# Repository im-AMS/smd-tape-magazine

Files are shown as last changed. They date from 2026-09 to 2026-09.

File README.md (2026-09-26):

# SMD Tape Magazine: parametric

A fully parametric FreeCAD model of an SMD component tape magazine for 8, 12
and 16 mm tape, plus a sticker generator that prints matching labels for each
magazine.

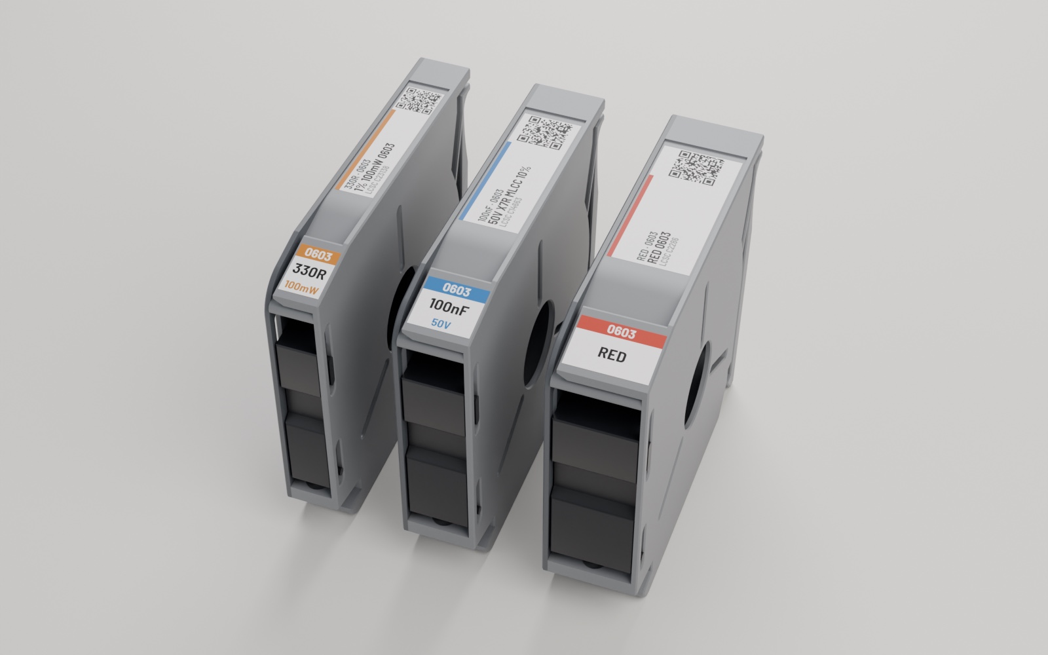
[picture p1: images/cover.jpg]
8, 12 and 16 mm magazines with stickers


| 8 mm magazine | lid latches |
|---|---|
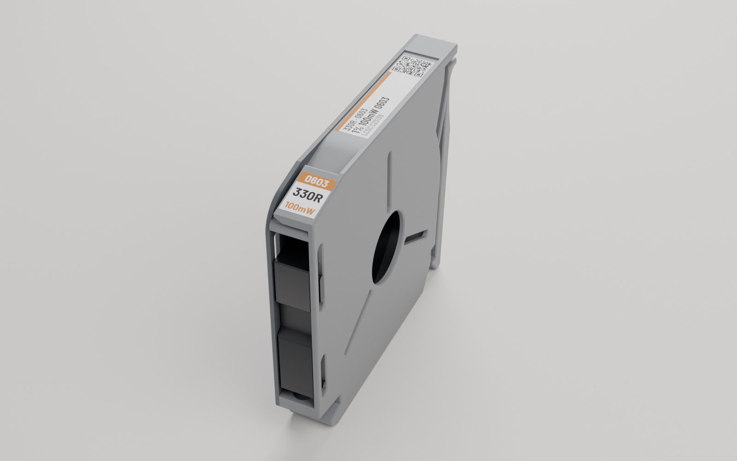
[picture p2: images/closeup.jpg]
8 mm magazine close-up
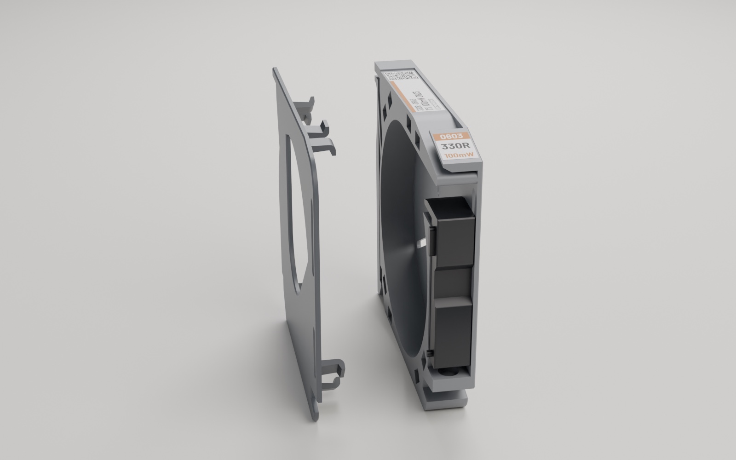
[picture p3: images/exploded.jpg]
Lid pulled off to show the snap pegs
|  |  |

## What's in here

| path | what |
|---|---|
| `print/` | print-ready STLs: `smd-magazine-body-{8,12,16}mm`, `smd-magazine-slider-{8,12,16}mm`, `smd-magazine-lid-all-sizes` |
| `print/rails/` | rails to stand the magazines in, from the two earlier versions of this design (their own licenses, see [rails/README](print/rails/README.md)) |
| `cad/smd-tape-magazine.FCStd` | the parametric FreeCAD model (FreeCAD 1.1+): magazine, lid, slider, parameters |
| `cad/latch-socket-cutter.FCStd`, `cad/latch-peg.FCStd` | the lid latch shapes, linked into the main file. Keep all three files together |
| `stickers/` | label generator: front + top stickers per part, laid out on A4 |
| `docs/DESIGN.md` | how the model is built, measured dimensions, and known traps |

## Print

**Print in PETG only.** The lid holds on with eight small snap pegs; PLA is
too brittle for them and they snap off.

The STLs are already oriented: the chamfered face goes on the bed (it's there
to absorb elephant's foot). No supports needed.

| setting | value |
|---|---|
| material | PETG |
| nozzle | 0.4 mm |
| layer height | 0.25 mm |
| walls | 3 |
| top / bottom shells | 3 / 3 |
| infill | 8–10% gyroid (a little infill makes the print itself more reliable) |
| supports | none |

**Tune your filament profile first**, especially **bridging and cooling**.
The latch sockets and pegs are small, and sagging bridges or under-cooled
overhangs are the usual cause of a lid that won't fit or won't stay on.

Per magazine: one body, one slider of the same width, one lid, and a spring.
For the rail, pick one from [`print/rails/`](print/rails/README.md).

### Loader (recommended)

Print Robin's [SMD Magazine Loader](https://www.printables.com/model/468303-smd-magazine-loader)
too. It makes refilling a magazine with tape quick and easy. **These
magazines are compatible with it**; the design they were remixed from is not.

### Fitting the lid

Press the lid on **evenly**, with something flat and stiff laid over it, e.g.
a ~3 mm mild steel plate, so all eight pegs snap in together. Pressing one
corner at a time bends the lid and can break a peg.

### Spring

The slider's spring bore is 8 mm deep, made for a longer spring than
upstream's. Upstream's spring is 0.3 mm wire × 4 mm OD × 20 mm with a 5 mm
bore. To use that one, set `spring_pocket` to 5 (see below).

## Customise

Open `cad/smd-tape-magazine.FCStd` in FreeCAD 1.1 or newer and double-click
`Parameters`. The sheet is colour-coded:

- **green: user inputs.** `tape_size` (8 / 12 / 16), `clearance`, `wall`,
  `spring_pocket`
- **yellow: fit tuning.** `peg_gap`: raise it if the lid is too tight to push
  on with your printer
- **grey: derived / internal.** Calculated from the above; don't type over them

After changing a value press **Ctrl+R** (Edit → Refresh). Then select the
`Magazine`, `Lid` or `Slider` body and export it as STL.

## Stickers

`stickers/` generates two labels per part from a CSV parts list: a front
label for the dispensing end and a top strip with value, package and a QR
code, sized to the magazine width.

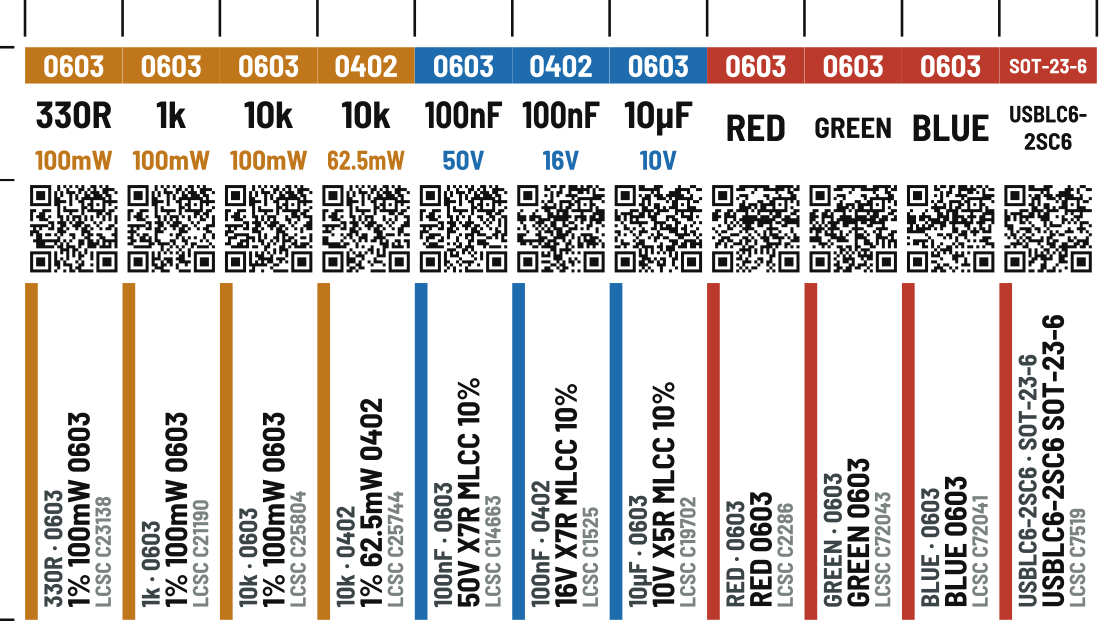
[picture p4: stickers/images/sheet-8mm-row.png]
Sticker sheet for 8 mm magazines


> **Test your QR codes first.** Before printing a full sheet, print
> `qr_scan_test_sheet.py` on your printer and sticker paper and scan it with your
> phone: QR codes this small depend on print resolution.

Print them on **glossy peel-off sticker paper** at your printer's **highest
quality** setting, at 100% scale.

Runs with [uv](https://docs.astral.sh/uv/):

```sh
cd stickers
uv run labels.py example.csv --out out
```

See [`stickers/README.md`](stickers/README.md) for examples, the CSV format
and options.

## Credits

- **Based on** [SMD Component Tape Magazine (8, 12, 16mm)](https://www.printables.com/model/580643)
  by **Lord Asdi**, licensed CC BY 4.0. The body outline was traced from its
  STL and the model rebuilt from scratch as a parametric design, with reworked
  lid latches, sockets and slider.
- **Inspired by** the Gen 2 SMD magazine by **robin7331**, whose original
  *SMD Component Magazines* is the design Lord Asdi's version remixes. Gen 2
  hasn't been released as open source; this is an open, parametric take on the
  same idea.
- **Rails** in `print/rails/` are by Lord Asdi (CC BY 4.0) and
  [OneGeekGuy](https://www.printables.com/model/1182844) (CC BY-NC 4.0),
  included unmodified.

## License

Everything I made here (3D model, STLs, sticker generator, images, docs) is
licensed under [CC BY-NC-SA 4.0](LICENSE):

- **Free** to print, share and remix, with credit
- **No commercial use**: don't sell the files or prints made from them
- **Remixes must use the same license**

Exceptions: the rails in `print/rails/` keep their authors' licenses (see
above), and the fonts in `stickers/fonts/` are under the SIL Open Font
License ([`OFL.txt`](stickers/fonts/OFL.txt)).

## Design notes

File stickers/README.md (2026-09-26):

# Magazine stickers

Generates two stickers per part from a parts list, laid out on A4 for cutting
with a knife and a ruler.

| sticker | size | face on the magazine | content |
|---|---|---|---|
| front | `W × 11` | small chamfer at the dispensing end | package, value, qualifier |
| strip | `W × 37` | angled top edge | value·package rule, headline, supplier + qty, QR |

`W` is the tape size (8 / 12 / 16 mm). Both lengths are fixed — only the width
tracks the feeder, which is why the two stickers share a column grid and can be
paired one cell per part.

> **Test your QR codes first.** Before printing a full sheet, print
> `qr_scan_test_sheet.py` on your printer and sticker paper and scan it with your
> phone: QR codes this small depend on print resolution.

**How to print them:**
- Use **glossy sticker paper**, the shiny kind with a backing you peel off.
  Small text and the QR codes stay crisp on it; plain paper blurs them.
- Set the printer to its **highest quality / best detail** setting.
- Print at **100% scale**, never "fit to page". Before cutting, measure the
  outermost cut ticks: `labels.py` prints the distance they must be apart
  (or add `--marks` for a 50 mm ruler on the sheet).

Stickers on 8, 12 and 16 mm magazines

## Examples

An 8 mm sheet made from [`example.csv`](example.csv): real LCSC parts
(resistors, capacitors, LEDs, an ESD diode), colour-coded by class. Each part
gets a front sticker (package band, value, rating) and a top strip (spec, LCSC
part number and a QR that opens the part's LCSC page).

8 mm sticker sheet

Close-up:

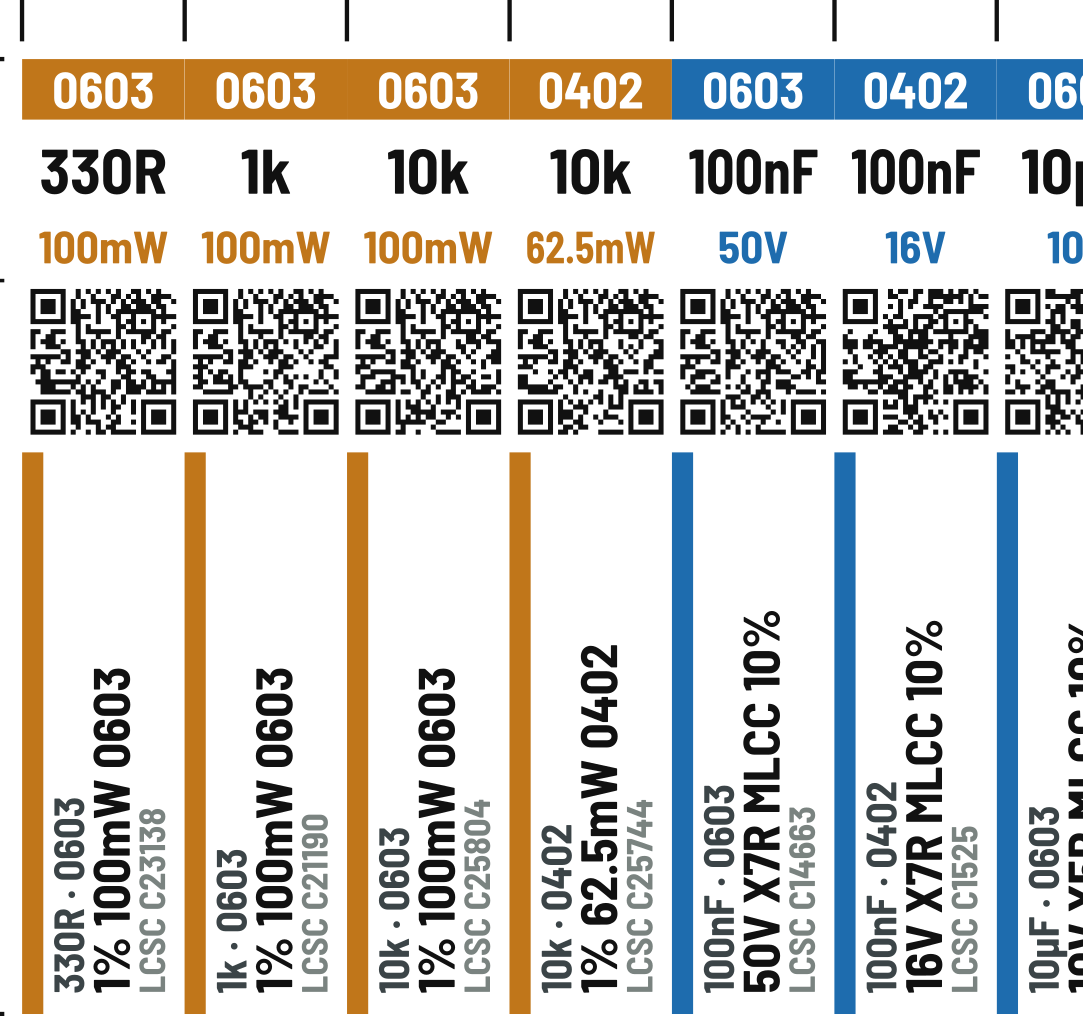
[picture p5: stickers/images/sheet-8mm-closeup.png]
Close-up of 8 mm stickers


The design test sheet (`design_test_sheet.py`). I printed it on sticker stock
and picked the current sizes from it:

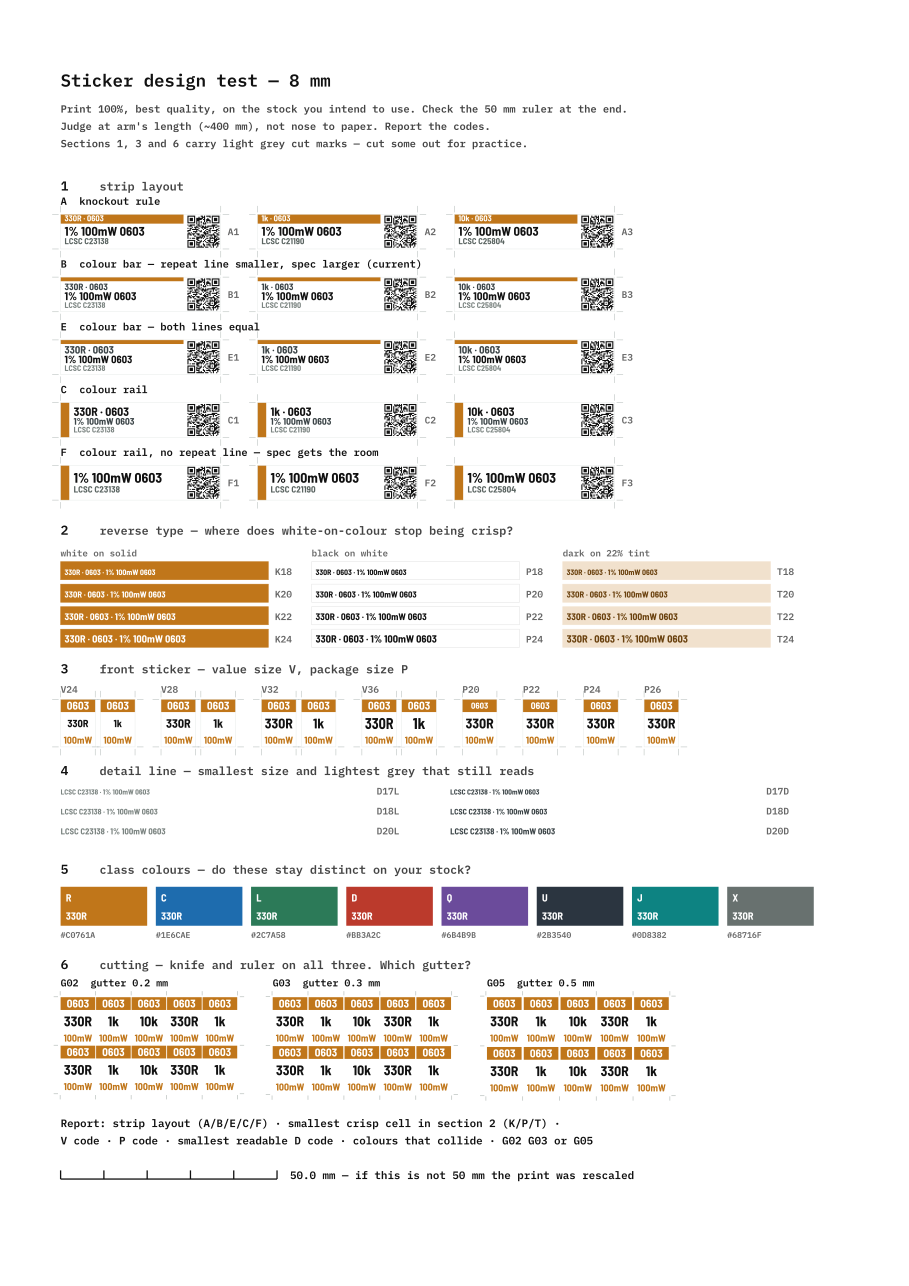
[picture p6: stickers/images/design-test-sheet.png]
Design test sheet


## Run

Needs [uv](https://docs.astral.sh/uv/). It installs Python and the
dependencies on first run.

```sh
uv run labels.py example.csv --out out                 # try it on the bundled example
uv run labels.py parts-template.xlsx --out out         # or fill in the Excel template
uv run labels.py "path/to/parts.csv" --out out --pdf
uv run qr_scan_test_sheet.py "path/to/parts.csv"       # print-and-scan diagnostic
uv run design_test_sheet.py "path/to/parts.csv"        # design experiment sheet
```

Fonts are bundled in `fonts/` (OFL) and text is converted to outlines, so
nothing needs installing and the PDF renders identically anywhere.

## Options

| flag | effect |
|---|---|
| `--feeder 12` | tape width for rows whose `feeder` cell is empty (or with no `feeder` column); 8 is the default |
| `--layout` | how mixed widths share sheets: `page`, `row` or `mixed` (see below). Asked interactively if omitted |
| `--gutter 0.5` | white between stickers; cuts run down its middle |
| `--supplier` | supplier for rows whose `supplier` cell is empty; `LCSC` is the default |
| `--qr-template` | link pattern for those rows, `{sku}` substituted; default is that supplier's built-in pattern |
| `--marks` | add a 50 mm ruler and footer to the sheet |
| `--pdf` | also run `inkscape` to produce PDF |

## Experiment sheet

`design_test_sheet.py` puts every open design question on one sheet (8 mm fits a
single A4; wider tapes flow onto a second page) so they can be settled in one
print. The sample stickers are the first parts in your CSV with the tested
width; `--feeder 12` picks the width (default: the first part's). Each cell is
coded so results can be reported without ambiguity:

| section | codes | question |
|---|---|---|
| 1 | `A1`–`F3` | strip layout: knockout rule, colour bar ×2, colour rail, or rail with no repeat line |
| 2 | `K16`–`K24`, `P`, `T` | reverse type vs positive vs dark-on-tint, 1.6–2.4 mm |
| 3 | `V24`–`V36`, `P20`–`P26` | front sticker value size and package size |
| 4 | `D17L`–`D20D` | detail line: size and grey vs dark |
| 5 | — | do the eight class colours stay distinct on your stock |
| 6 | `G02`, `G03`, `G05` | gutter width — cut all three and see |

Sections 1, 3 and 6 carry light grey corner crop marks so real stickers can be
cut out of the experiment sheet for practice. The marks are `#B9C0BD`, light
enough to cut straight through without leaving a visible edge — cut guides
belong outside the artwork, and never in black next to it.

Reverse type is the hard case: ink spreads into white strokes and thins them, so
white-on-colour fails at a larger size than black-on-white. Section 2 finds where.

## Type — settled by print test

Sizes are not theoretical; they were chosen off a printed experiment sheet
(glossy sticker stock, MP tray, best quality) and are fixed constants in
`labels.py`. Strings that will not fit are demoted individually by `_fit_step`
rather than shrinking every sticker on the sheet.

| what | size | experiment code |
|---|---|---|
| front value | 3.2 mm | V32 |
| front package | 2.6 mm | P26 |
| front qualifier | 2.3 mm | — |
| strip line 1 (repeat) | 2.15 mm | layout B |
| strip line 2 (spec) | 2.6 mm | layout B |
| strip detail | 1.85 mm light grey | D18L, floor D17L |

**Strip layout B**: a plain colour bar with every character on white. Line 1
repeats the front sticker so it is demoted and greyed; line 2 is the spec, the
only thing the strip says that the front sticker does not.

Reverse type tested fine on glossy stock, which is why the front sticker's
package band is still white on solid colour. On plain paper it was the weakest
element on the sheet — the stock, not the design, was the problem.

## Cutting and bleed

`--gutter` (default 0.25 mm) sets the gap between stickers and the cut runs down
its middle, so every boundary is still a single straight full-sheet cut.

The gap is **not white**. Each sticker's edge colour is extended by half the
gutter, so the two bleeds meet exactly on the cut line. A cut that drifts then
shows colour rather than a white sliver, which is what reads as a printing
fault. Because the parts list is grouped by class, most neighbours share a
colour and most cut lines are invisible; only a class change leaves a two-colour
seam, and drifting there picks up the neighbour's hue rather than white.

The QR needs no special handling. Nothing coloured is allowed within 0.8 mm of
it, so its bleed is white — which is exactly what a quiet zone is. The 0.3 mm
quiet zone at the trim line only grows if the cut drifts outward. Long ticks mark cell edges, short ticks the split between a
part's front sticker and its strip.

## Input

A spreadsheet (`.xlsx`) or a CSV with a header row.

**Easiest: fill in [`parts-template.xlsx`](parts-template.xlsx)** in Excel,
LibreOffice or Google Sheets. It has dropdowns for `kind`, `feeder`,
`tolerance` and `footprint`, a note on every column header, and highlights a
row that has a `kind` but no `value` (or the reverse). Values outside the
dropdowns are allowed; you only get a warning. `labels.py` reads its `parts`
sheet directly (or the first sheet of any other workbook). The template is
built by `make_template.py` from `example.csv`.

Columns are matched **by name**, in any order and any case; only `kind` and
`value` are required:

| column | example | notes |
|---|---|---|
| `kind` | `R`, `C`, `LED`, `IC` | picks the class colour (see below) |
| `value` | `330`, `100n`, `USBLC6-2SC6` | long values wrap onto two lines at a space or hyphen. A value that still does not fit stops the run with an error naming the row; nothing is ever printed shortened |
| `tolerance` | `1%` | |
| `rating` | `100m`, `50v X7R` | power for resistors, voltage/dielectric for caps |
| `subtype` | `MLCC` | |
| `footprint` | `0603` | also accepted as `package` |
| `supplier` | `LCSC`, `DigiKey`, `Mouser`, `Robu` | who the `sku` belongs to; decides the QR link (see QR below). Empty = `--supplier` (LCSC) |
| `sku` | `C23138`, `497-5235-1-ND` | supplier part number; printed on the strip, and used to build the QR link |
| `url` | `robu.in/?s=R178998&post_type=product` | full product link for the QR. Needed for suppliers without a built-in link; overrides it for the others |
| `quantity` | `21-30` | for your own stock keeping. **Never printed** on the sticker: a count goes stale, the sticker doesn't |
| `feeder` | `8`, `12`, `12mm` | tape width in mm, any value; empty uses `--feeder` |

Unknown columns are ignored (and listed as a warning). A header name that
appears twice is an error, so a column is never picked by guesswork.

`kind` maps to a class (R C L D Q U J X) which picks the colour and decides the
strip headline: passives lead with their spec, semiconductors lead with the part
number. Values are normalised on the way in — `100n` → `100nF`, `330` → `330R`.

Each row can come from a different supplier. The strip shows the supplier name
and `sku` (e.g. `LCSC C23138`), and the QR opens that part's page:

| `supplier` | QR link built from `sku` |
|---|---|
| LCSC (or empty) | `lcsc.com/product-detail/{sku}.html` |
| DigiKey | `digikey.com/en/products/result?keywords={sku}` |
| Mouser | `mouser.com/ProductDetail/{sku}` |
| anything else | none: put the full link in `url` (otherwise a warning, and no QR) |

Each pattern was checked by opening a real part in a browser. Links carry no
`https://` or `www.`: every character makes the QR denser, and the browser adds
them. Some camera apps show a scheme-less link as plain text, so check yours with
`qr_scan_test_sheet.py` (section 3 prints it with and without `https://`).

## Mixed tape widths

Every sticker is the same height; only its width follows the part's `feeder`.
When a CSV has more than one width, `labels.py` asks how they should share
sheets (or pass `--layout`):

| layout | what you get | cutting |
|---|---|---|
| `page` | one width per page | as usual: every column lines up down the whole sheet |
| `row` | rows may differ, a row never mixes widths | each row has its own column ticks, in the gap above and below it |
| `mixed` | any widths side by side; tightest packing | same as `row` |

For `row` and `mixed`, parts stay in **CSV order** whenever that costs no extra
rows; otherwise they are reordered to pack tighter, and the summary says which.
Rows are 8 mm apart to hold their ticks, so a page holds 4 rows instead of 5.
Cut with the sheet intact (through the sticker layer, not the backing) so every
tick stays usable.

## QR

Payload length decides the symbol version, version decides the module count, and
module count decides whether it survives printing. The strip width is a hard
ceiling on the box, because a QR is square and cannot use the 37 mm length.

Measured on an inkjet, normal quality, plain paper, iOS camera:

| module size | result |
|---|---|
| 0.336 mm (8.4 mm box, 29 mod) | scanned |
| 0.269 mm (7.8 mm box, 29 mod) | did not scan |
| 0.248 mm (7.2 mm box, 29 mod) | scanned only with effort |

Working floor at normal quality on plain paper is roughly **0.29 mm per
module**. An 8 mm strip gives a 7.4 mm box, and the LCSC link is 35 bytes, which
is a version 3 symbol: **0.255 mm**. That is below the plain-paper floor; it
relies on best quality on glossy sticker stock.

### The QR warning

`labels.py` works out every part's module size (its link length and its tape
width) and prints a loud **QR WARNING** for any below **0.25 mm**
(`QR_MIN_MODULE`), i.e. anything denser than the LCSC default on 8 mm. This is
a guard against links *worse* than what has been printed, not a guarantee: run
`qr_scan_test_sheet.py` on your printer and stock. A link too long for any QR
at all stops the run.

| link on 8 mm tape | chars | mm/module | |
|---|---|---|---|
| LCSC | 35 | 0.255 | ok |
| Mouser | 40 | 0.255 | ok |
| DigiKey | 53 | 0.255 | ok, but at the limit: a part number over 13 characters tips it into a denser code (0.224, warning) |

**The URL cannot get much shorter.** `lcsc.com` without `www` already redirects,
and version 2 holds only 32 bytes at ECC L. Uppercasing the URL would switch it
to the denser alphanumeric mode, but LCSC's path is case-sensitive: an
uppercase path lands on the catalogue page, not the part.

### If 0.255 mm will not scan

The one remaining lever is a short redirect on a host you own. A path-style URL
in uppercase stays in alphanumeric mode and holds version 1:

| payload | chars | version | mm/module @ 7.4 |
|---|---|---|---|
| `lcsc.com/product-detail/C23138.html` | 35 | 3 | 0.255 |
| `HTTP://EXAMPLE.SH/C23138` | 24 | 1 | **0.352** |

That is a 38% larger module in the same box — comfortably past your floor.

A Cloudflare Worker is enough:

```js
export default {
  fetch(request) {
    const sku = new URL(request.url).pathname.slice(1).toUpperCase();
    if (!sku) return new Response("no sku", { status: 404 });
    return Response.redirect(
      `https://lcsc.com/product-detail/${sku}.html`, 301);   // a redirect needs the full URL
  },
};
```

Point a short domain at it, then generate with:

```sh
uv run labels.py parts.csv --qr-template "HTTP://EXAMPLE.SH/{sku}"
```

Uppercase in the template is deliberate and required — one lowercase character
drops the payload into byte mode and costs you the version 1 symbol. Scheme and
host are case-insensitive so the link still resolves. Verify that your scanner
linkifies the uppercase form before committing a sheet.

## Printing

Print at 100%, best/high quality, on glossy sticker paper. Check the scale
before committing sticker paper: `labels.py` prints how far apart the outermost
cut ticks must be, or add `--marks` for a 50 mm ruler.

Cut ticks sit in the margins, never on a sticker. Long ticks are cell edges,
short ticks the split between a part's front sticker and its strip.

Content is kept 20 mm clear of the trailing edge (`MARGIN_Y`, `FOOTER_Y`),
because that is the margin inkjets clip.

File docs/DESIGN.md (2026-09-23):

# Design notes

How the FreeCAD model is built, and the traps found while building it. Read
this before editing anything beyond the `Parameters` sheet.

The geometry started from the STL of
[SMD Component Tape Magazine (8, 12, 16mm)](https://www.printables.com/model/580643)
by Lord Asdi. That model is STL only, so the outline was traced from the mesh
and everything else was rebuilt as a driven model. The traced outline is now
plain sketch geometry; the mesh is no longer in the file.

FreeCAD 1.1.3.

## Files

| path | what |
|---|---|
| `cad/smd-tape-magazine.FCStd` | **the main file**. Holds the `Magazine`, `Lid` and `Slider` bodies and the `Parameters` sheet |
| `cad/latch-socket-cutter.FCStd` | the socket cutter. One solid, used 8× to cut the latch sockets |
| `cad/latch-peg.FCStd` | the peg. One solid, used 8× on the lid |

**Keep the three `.FCStd` files together in `cad/`.** `smd-tape-magazine.FCStd` links to
`latch-socket-cutter.FCStd` and `latch-peg.FCStd` by relative path. Moving all three
together is fine; separating them breaks the binders.

## Object names vs labels

FreeCAD can't rename an object's internal name, only its label (what the tree
shows). Expressions use internal names, and so does this document. Lookup:

| internal name | label in the tree | what it does |
|---|---|---|
| `Body001` | Magazine | the magazine body |
| `Sketch001` / `Pad` | OutlineSketch / Blank | full-thickness slab from the side outline |
| `Sketch002` / `Pocket` | ReelCavitySketch / ReelCavity | hollows the body, leaving the `wall` front web |
| `Sketch003` / `Pocket001` | TopRightRecessSketch / TopRightRecess | 1.2 mm recess at the top-right of the back face |
| `Sketch004` / `Pocket002` | SpringSeatSketch / SpringSeat | seat for the lower end of the slider spring |
| `Chamfer`, `Fillet`…`Fillet003`, `Chamfer003` | TopRightRecessChamfer, RightEdgeFillet, TopEdgeFillet, TopRightRecessFillet, TopRightCornerFillet, LeftCornerChamfer | edge breaks |
| `SocketCut` / `Plug1..8` | LatchSockets / SocketCutter1..8 | cuts the 8 lid sockets |
| `JointPlacement` | LatchPositions | where the 8 latches sit |
| `Chamfer004` | MagazineFirstLayerChamfer | 0.3 mm elephant's-foot chamfer on the bed face |
| `Body002` | Lid | the lid |
| `BodyRef` | LidMagazineRef | binder of the magazine (reference only) |
| `Sketch006` / `Pad001` | LidOutline / LidPlate | the lid plate |
| `PegFuse` / `Peg1..8` | LatchPegs / LatchPeg1..8 | fuses the 8 snap pegs |
| `Chamfer005` | LidFirstLayerChamfer | elephant's-foot chamfer |
| `Body003` | Slider | the slider |
| `SliderRef` | SliderMagazineRef | binder of the magazine; `Sketch007` attaches to it |
| `Sketch007` / `Pad002` | SliderProfile / SliderBlank | slider body |
| `Sketch008` / `Pad003`, `Sketch009` / `Pad004` | BackGuideRib…, FrontGuideRib… | the ribs on each side |
| `Sketch010` / `Pocket003` | SpringBoreSketch / SpringBore | spring bore, depth `spring_pocket` |
| `Chamfer001`, `Chamfer002` | SliderTopChamfer, SliderTopEdgeBreak | top of the slider |
| `Chamfer006` | SliderFirstLayerChamfer | elephant's-foot chamfer |
| `Params` | Parameters | the spreadsheet |

## Parameters

All in `smd-tape-magazine.FCStd` → `Parameters` (internal name `Params`). The sheet is split into colour-coded sections
(FreeCAD spreadsheets have no read-only cells, so this is by convention):

| section | alias | value | drives |
|---|---|---|---|
| **User inputs** (green) | `tape_size` | 8 | SMD tape width — 8 / 12 / 16 |
| | `clearance` | 1 | tape channel clearance |
| | `wall` | 1.2 | body front web, lid plate, slider peg pads |
| | `spring_pocket` | 8 | slider spring bore (original design uses 5; longer springs here) |
| **Fit tuning** (yellow) | `peg_gap` | 0.4 | peg clearance off the flat mating face |
| **Derived** (grey) | `thickness` | `=tape_size + clearance + wall` | |
| | `peg_center_y` | `=(5.12 - 4.71) / 2` | centres the peg across the mating edge |
| **Internal** (grey) | `joint_marker_len` | 2 | length of the `JointPlacement` construction lines (cosmetic) |

**Don't move aliased cells by clearing and re-setting the alias.** Clearing an
alias silently rewrites every expression that used it to the raw cell address
(`Params.joint_marker_len` → `Params.B8`). Undoing that leaves the alias
property unregistered and downstream features go Invalid.

Verified working across `tape_size` 8/12/16 — thickness tracks, sockets and
pegs follow the back face, all bodies stay valid single solids.

**After editing a spreadsheet cell, force a recompute** (right-click the
document → Mark to recompute → refresh). Values do not propagate reliably on
their own, and edits silently queue up and land together later.

## How it's put together

```
Body001 (magazine)          lid (Body002)              slider (Body003)
  Pad          <- thickness   BodyRef   -> Body001       SliderRef -> Body001
  Pocket       <- wall        Sketch006 + Pad001 <- wall Pad002 <- tape_size + clearance/2
  ...                         PegFuse (8 pegs)           Pad003/Pad004 <- wall
  SocketCut (8 sockets)                                  Pocket003 <- spring_pocket
  JointPlacement
```

### Joint placement is sketch-driven

`JointPlacement` (in `Body001`) holds **8 construction lines** — start point is
the joint origin, direction is the mating edge. Both the socket and its lid peg
read from it:

```
Plug<n>.Base.x/.z = JointPlacement.Geometry[n-1].StartPoint.x/.y
Peg<n>.Base.x/.z  = same + peg_gap and peg_center_y offsets
```

So moving a joint moves the socket **and** its peg together — they cannot drift
apart. Dimensioned as position (X, Y) + length (parameter) + angle, so moving a
joint is two numbers:

| joint | constraints (X, Y) | joint | constraints (X, Y) |
|---|---|---|---|
| 1 | `[0]`, `[1]` | 5 | `[16]`, `[17]` |
| 2 | `[4]`, `[5]` | 6 | `[20]`, `[21]` |
| 3 | `[8]`, `[9]` | 7 | `[24]`, `[25]` |
| 4 | `[12]`, `[13]` | 8 | `[28]`, `[29]` |

### Cross-body references use SubShapeBinders

`BodyRef`, `SliderRef`, `Plug1..8`, `Peg1..8` are all
`PartDesign::SubShapeBinder`, `BindMode = Synchronized`. Edit `latch-socket-cutter` and
all 8 sockets update; edit `latch-peg` and all 8 pegs update.

Dependency flows one way: `smd-tape-magazine → latch-socket-cutter / latch-peg`.

## Key measured dimensions

Recovered from the original STL:

- thickness = tape width + 2.000; the 8/12/16 bodies share an identical XZ profile
- hub bore r = 7.500 @ (0.40264, 32.50537)
- reel recess r = 30.000, same centre, 8.800 deep
- three radial slots, w = 2.000, r = 1.000, at exactly 90° / 210° / 330°
- **8** lid snap sockets: mouth 3.4292 at the back face → 11.73° lead-in →
  crest 2.3500 → **65.22° retaining undercut** → cavity 3.6500 to the floor
- socket cutter 5.12 long; peg 4.71 → 0.41 slack, split evenly by `peg_center_y`

## Traps worth remembering

**Never let a mesh become a Body's `BaseFeature`.** A mesh-derived solid is
invalid (the original had 3728 triangle faces); PartDesign features that fuse
against it can come out **empty**, with no error. The pad preview looks fine
because it doesn't run the fuse. Until 2026-09-23 `Body001` still had the
refined STL solid as its BaseFeature, with `Sketch001`/`002`/`005` projecting
~74 edges from it. Those projections were frozen into plain sketch geometry (and the unused `Sketch005` deleted)
and the whole mesh chain was deleted. The body is identical at 8/12/16
(symmetric difference 0 mm³), and the file shrank from 4.7 MB to 0.8 MB.

**Deleting a BaseFeature invalidates edge names downstream.** FreeCAD's
topological names include the history, so after the delete `Fillet` pointed at
an edge name that no longer existed. The recompute stopped there, silently
leaving everything after it at the old size. Each dress-up feature had to be
re-pointed. The indices happened to come out the same, but only the stale
hash was wrong. Always re-run a full 8→12→16 check after structural edits and
confirm the thickness actually changed.

**Coplanar faces break booleans.** Cutters landing exactly on a face fail
non-deterministically — 3 of 8 sockets came out as sealed internal voids, and 3
of 8 pegs refused to fuse. Fix is a 0.05 mm overshoot, baked into the
`Plug`/`Peg` Y expressions. Check `len(Shape.Shells) == 1` — sealed voids report
`valid=True` and give no error.

**`Pocket` with `UpToFace` silently fails below ~0.25 mm offset.** Reports
`Up-to-date` and `valid=True` while keeping the *previous* geometry.

**Don't leave a loose sketch next to a PartDesign Boolean.** A tree edit can
pull it into the Boolean's tool group, which invalidates it and silently drops
the tip. Symptom: body volume jumps ~855 mm³ and the sockets stop being cut.
Check `SocketCut.Group` holds only the 8 binders.

**Sketches attached to binder geometry are fragile.** `lid/Sketch006` used to
be attached to `BodyRef.Face122`, with its lid outline projected from ~28
`BodyRef` edges. Adding `Chamfer003`/`Chamfer004` to the body renamed those
edges, and every recompute then logged "External geometry … missing
reference" for the whole outline (the red errors after a `tape_size` change).
Fixed 2026-09-23: the outline is now the sketch's own geometry (Block-constrained,
identical edges), and the sketch is unattached with
`Placement.Base.y = -Params.thickness`. The trade-off is that **the lid outline
no longer follows edits to the body outline.** Change `Body001/Sketch001`'s
outline and you must update `Sketch006` to match.

**Chamfers and fillets on the body reference edges by name.** Verified at
8/12/16 that they all land on the same geometric edges. Re-check after adding
any feature upstream of them. `Chamfer003` had `Edge199` (a tangent edge that
FreeCAD always skipped) removed; the result is unchanged.

## Latch fit — current understanding

Printed tabs were hard to insert and some broke. Measured causes:

1. **Zero clearance on the flat mating face** — 5.2 mm of zero-gap sliding
   contact. Addressed by `peg_gap = 0.4`.
2. **0.374 mm of forced compression** — the barb crest (2.724) must pass the
   socket constriction (2.350) with nowhere to flex.
3. **Square leading tip** at 90°, no chamfer, so the barb hits the female taper
   as a sharp corner.

Moving the peg does **not** fix (2): it gains room to deflect but pushes the
barb the same distance further in, so net compression stays 0.374. Only widening
the female relieves it. This was studied in a separate overlay file that is not
part of this repo.

The 65.0° barb ramp and 65.3° female undercut are a matched **retention** pair.
Leave them alone; softening them trades insertion force for a lid that pops off.

## Socket wall thickness

Measured at mid-socket depth, thinnest wall per joint:

| joint | wall | perimeters @ 0.4 mm |
|---|---|---|
| 1 | 1.199 | 3.00 |
| 2 | 1.592 | 3.98 |
| 3 | 1.977 | 4.94 |
| 4 | 2.723 | 6.81 |
| 5 | 1.205 | 3.01 |
| 6 | 1.199 | 3.00 |
| 7 | 1.609 | 4.02 |
| 8 | 1.968 | 4.92 |

Aim for whole multiples of the extrusion width. A wall of e.g. 1.344 is 3.36
perimeters — the 0.36 remainder becomes gap-fill, which is a common stringing
source. Joints 1, 5, 6 were nudged onto 1.200 (exactly 3) for this reason.

Note the female relief above would **subtract** from these.

## Open items

- [ ] Female relief not applied. `latch-socket-cutter.FCStd` is untouched; the relief
      was only studied
- [ ] `latch-socket-cutter` and `latch-peg` pad lengths (5.12 / 4.71) are plain values,
      not linked to `peg_center_y`. Change one and update the formula by hand
- [ ] `slider/Sketch009` has zero geometry yet drives `Pad004`. Worth checking
- [ ] Sketches `Sketch002`–`004`, `Sketch007`–`010` are still attached to faces
      by name (`Face59`, `Face72`, …). They hold at 8/12/16 but are the next
      thing to break if features are added upstream

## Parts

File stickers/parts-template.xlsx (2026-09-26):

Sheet: parts
kind | value | tolerance | rating | subtype | footprint | supplier | sku | url | quantity | feeder
R | 330 | 1% | 100m |  | 0603 | LCSC | C23138 |  |  | 8
R | 1k | 1% | 100m |  | 0603 | LCSC | C21190 |  |  | 8
R | 10k | 1% | 100m |  | 0603 | LCSC | C25804 |  |  | 8
R | 10k | 1% | 62.5m |  | 0402 | LCSC | C25744 |  |  | 8
C | 100n | 10% | 50v X7R | MLCC | 0603 | LCSC | C14663 |  |  | 8
C | 100n | 10% | 16v X7R | MLCC | 0402 | LCSC | C1525 |  |  | 8
C | 10u | 10% | 10v X5R | MLCC | 0603 | LCSC | C19702 |  |  | 8
LED | RED |  |  |  | 0603 | LCSC | C2286 |  |  | 8
LED | GREEN |  |  |  | 0603 | LCSC | C72043 |  |  | 8
LED | BLUE |  |  |  | 0603 | LCSC | C72041 |  |  | 8
ESD | USBLC6-2SC6 |  |  |  | SOT-23-6 | LCSC | C7519 |  |  | 8

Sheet: how to use
SMD magazine stickers: parts list
1. Fill in the 'parts' sheet, one row per part. The example rows can be deleted.
2. Only kind and value are required. Hover over a column header for what it means.
3. Dropdowns suggest common values; anything else is allowed (you get a warning).
4. Red cells: a row with a kind but no value (or the other way round), or a
supplier without a built-in link (not LCSC/DigiKey/Mouser) and no url.
quantity is for your own records: it is never printed.
5. Save, then run: uv run labels.py parts-template.xlsx --out out --pdf
Keep the sheet name 'parts' and the header row. Columns can be reordered; extra
columns are ignored. A CSV with the same header row works too.

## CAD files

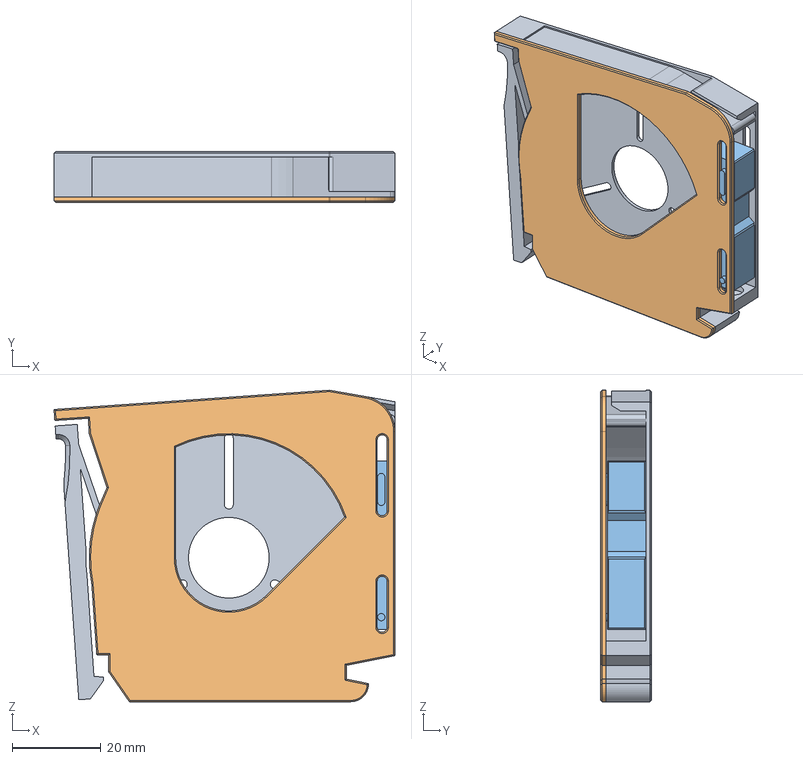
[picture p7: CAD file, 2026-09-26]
cad/smd-tape-magazine.FCStd
77.0 x 11.4 x 70.3 mm
Magazine
Lid
Slider

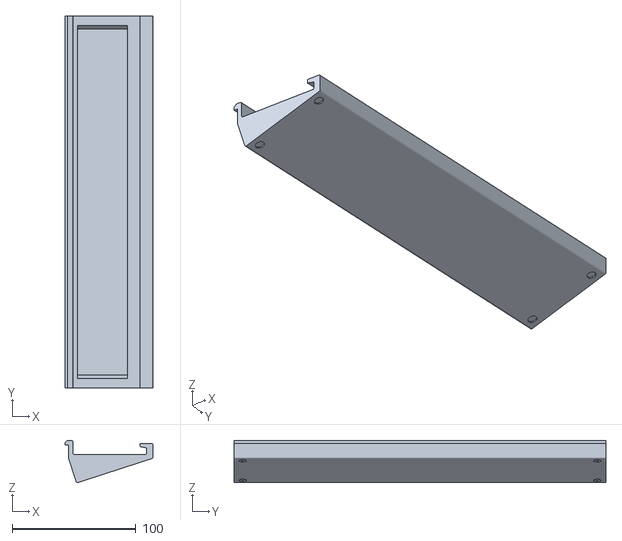
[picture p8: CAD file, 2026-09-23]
print/rails/lord-asdi/rail_300mm.stl
70.7 x 300.0 x 34.2

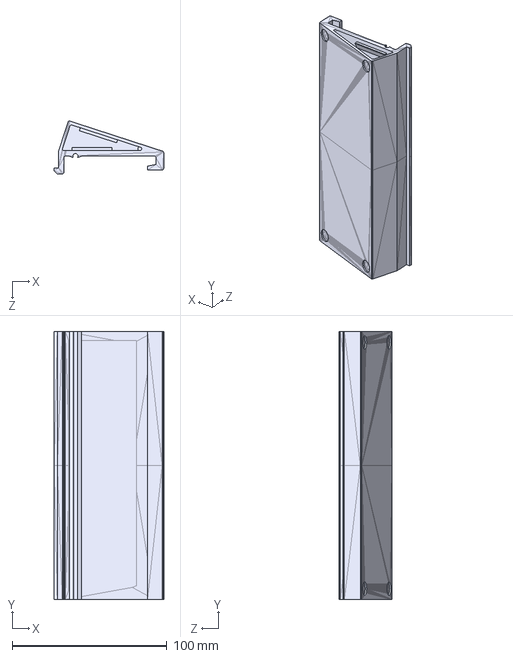
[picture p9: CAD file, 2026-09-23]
print/rails/onegeekguy/railupdated.step
70.7 x 173.0 x 34.2 mm

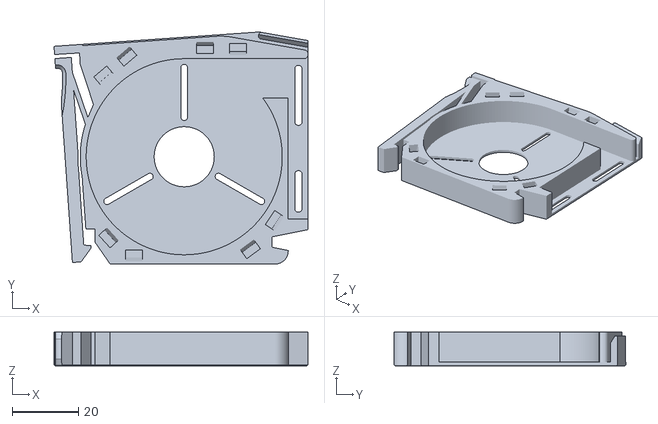
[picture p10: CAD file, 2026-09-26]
print/smd-magazine-body-8mm.stl
77.0 x 70.3 x 10.2

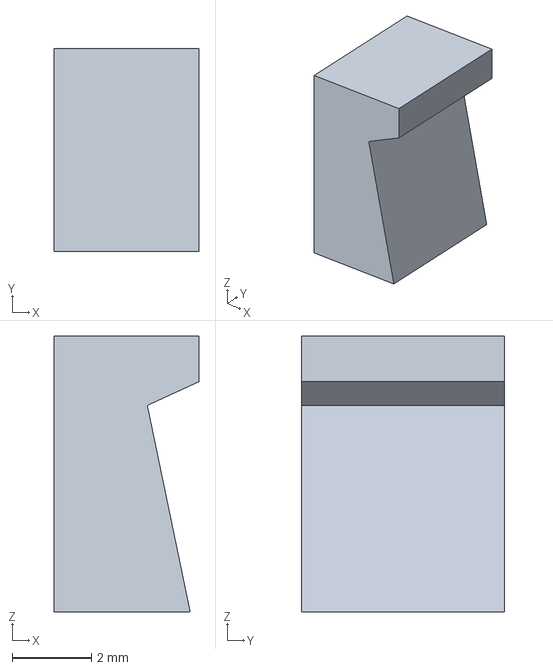
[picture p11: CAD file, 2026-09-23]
cad/latch-socket-cutter.FCStd
3.65 x 5.12 x 6.95 mm

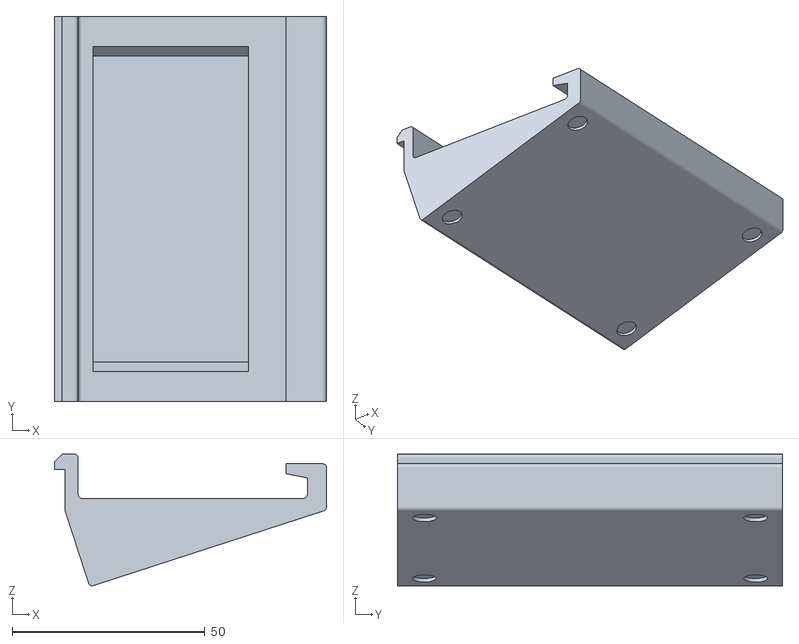
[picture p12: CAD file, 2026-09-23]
print/rails/lord-asdi/rail_100mm.stl
70.7 x 100.0 x 34.2

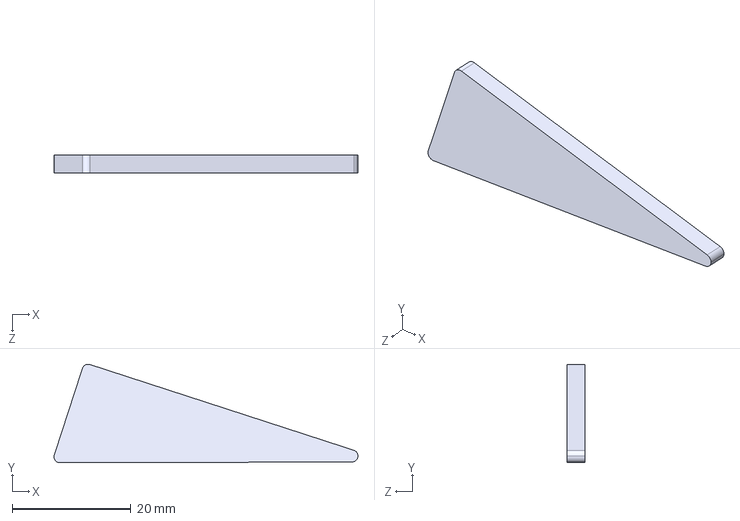
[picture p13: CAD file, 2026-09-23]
print/rails/onegeekguy/railcap.step
51.1 x 16.6 x 3.00 mm

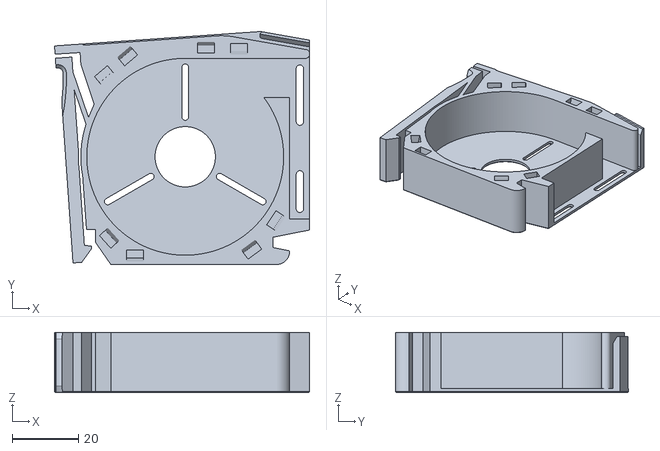
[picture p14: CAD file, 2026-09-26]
print/smd-magazine-body-16mm.stl
77.0 x 70.3 x 18.2

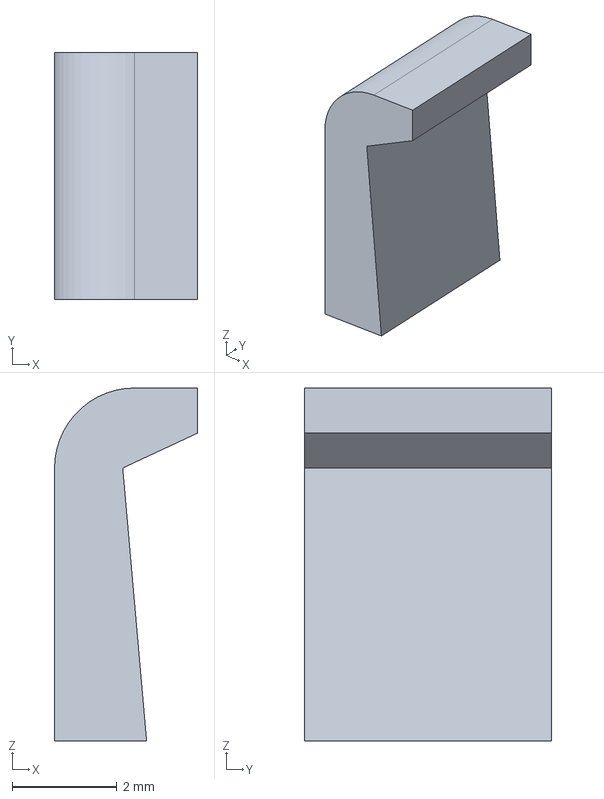
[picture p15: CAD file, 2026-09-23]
cad/latch-peg.FCStd
2.72 x 4.71 x 6.72 mm

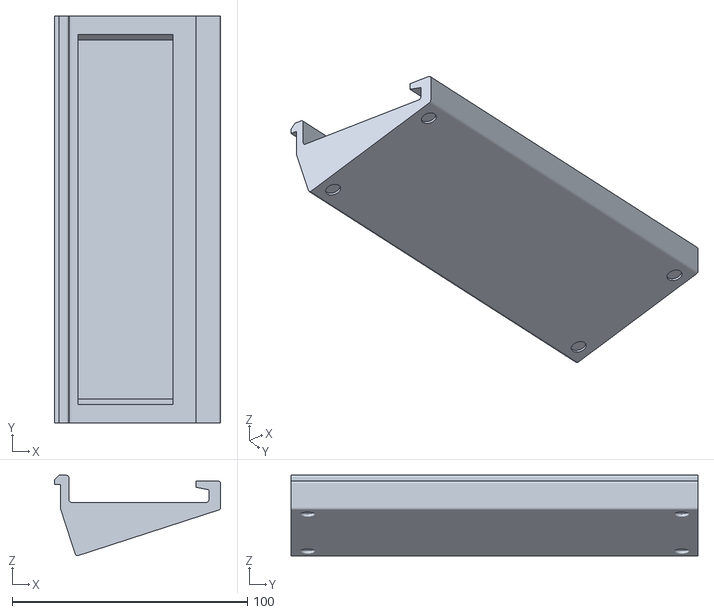
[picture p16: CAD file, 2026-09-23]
print/rails/lord-asdi/rail_176mm.stl
70.7 x 173.0 x 34.2

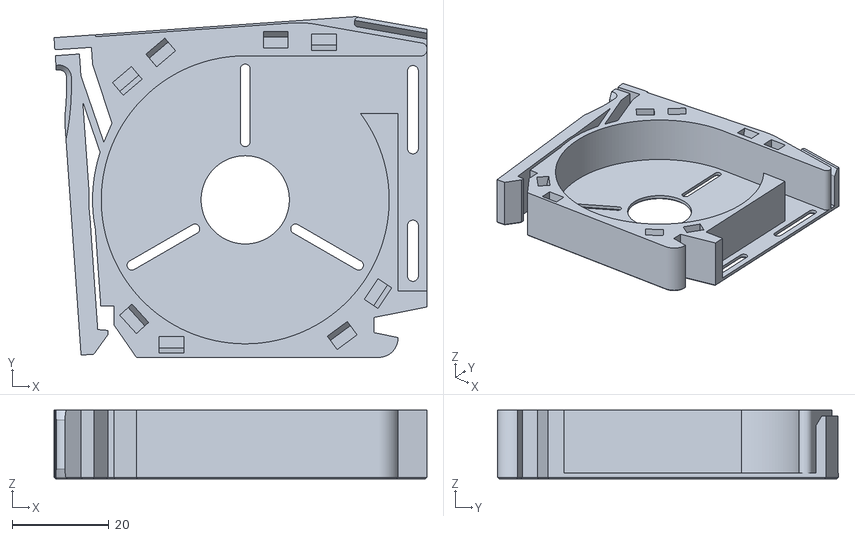
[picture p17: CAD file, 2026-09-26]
print/smd-magazine-body-12mm.stl
77.0 x 70.3 x 14.2

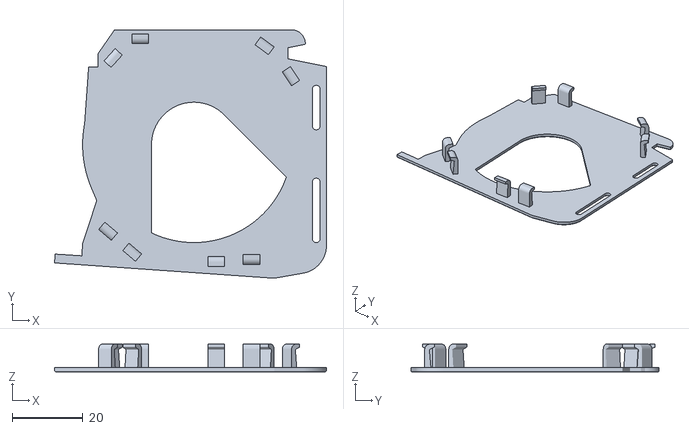
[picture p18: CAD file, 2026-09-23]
print/smd-magazine-lid-all-sizes.stl
77.0 x 70.3 x 7.88

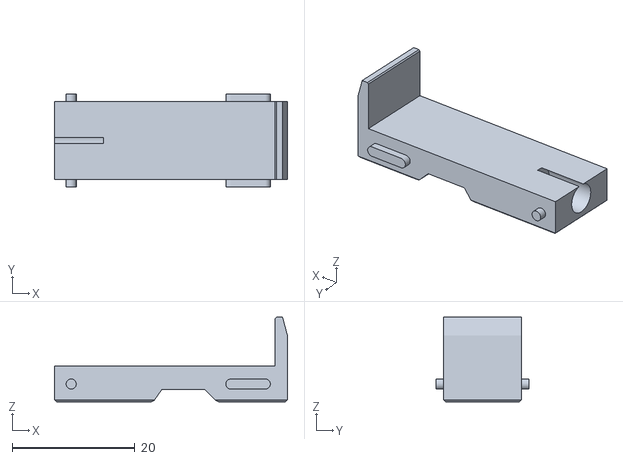
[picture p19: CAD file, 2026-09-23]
print/smd-magazine-slider-12mm.stl
38.0 x 15.1 x 13.8

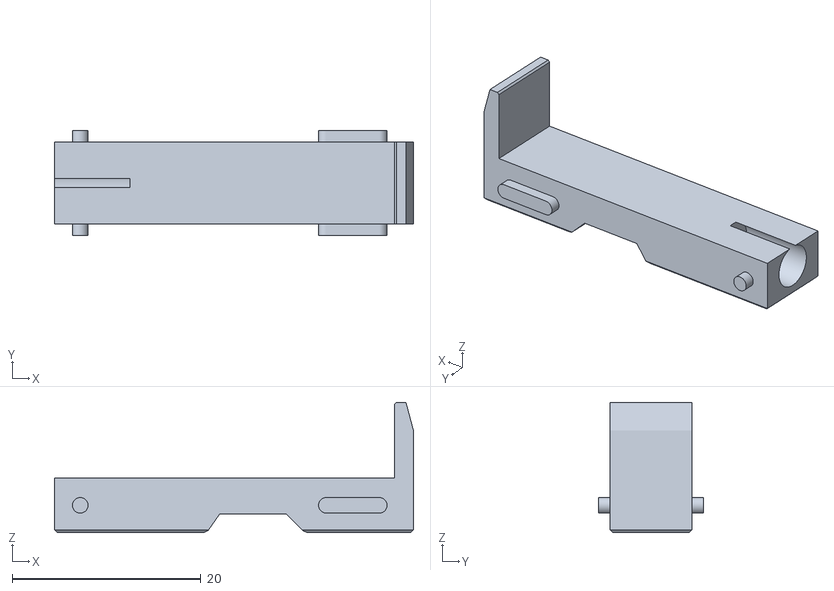
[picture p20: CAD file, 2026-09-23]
print/smd-magazine-slider-8mm.stl
38.0 x 11.1 x 13.8

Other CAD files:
print/smd-magazine-slider-16mm.stl

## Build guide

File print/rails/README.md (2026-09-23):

# Rails

The magazines stand in a rail. I didn't design one; these are the rails from
the two earlier versions of this magazine, included unmodified so you can
pick whichever you prefer. **They keep their original licenses**, which are
different from the rest of this repo.

## `lord-asdi/`: the original rails

From [SMD Component Tape Magazine (8, 12, 16mm)](https://www.printables.com/model/580643)
by **Lord Asdi**. License: **CC BY 4.0**.

| file | rail length |
|---|---|
| `rail_100mm.stl` | 100 mm |
| `rail_176mm.stl` | 176 mm |
| `rail_300mm.stl` | 300 mm |

This magazine's outline was traced from Lord Asdi's body, so these rails
match its feet.

## `onegeekguy/`: rail with O-ring grip

From [SMD Magazine 8/12/16mm Modified Easy Print](https://www.printables.com/model/1182844)
by **OneGeekGuy**. License: **CC BY-NC 4.0**.

| file | what |
|---|---|
| `railupdated.step` | rail with a groove for an O-ring to grip the magazines; it can be filled with sand or concrete for weight |
| `railcap.step` | end cap for the rail |

Needs an O-ring: R32, 3.4/3.5 mm (per the original listing). Most slicers
open STEP directly.

This rail was designed for OneGeekGuy's remix, whose feet were changed to
9 mm. **I haven't tested it with this magazine.**

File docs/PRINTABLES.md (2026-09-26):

# Printables listing (copy-paste)

**Name:** SMD Tape Magazine 8/12/16mm: Parametric (FreeCAD) + Sticker Generator

**Remix of:** https://www.printables.com/model/580643 (SMD Component Tape Magazine by Lord Asdi)
and https://www.printables.com/model/1182844 (SMD Magazine Modified Easy Print by OneGeekGuy, for its rail)

**Category:** Hobby & Makers > Electronics

**Tags:** smd, smt, electronics, organizer, organization, smdcomponents, parametric, freecad, labels

**License:** Creative Commons, Attribution-NonCommercial-ShareAlike 4.0

**Files to upload:** everything in `print/` (including `print/rails/`), plus `cad/*.FCStd` (all three together)

**Images:** `images/cover.jpg` (cover), `images/closeup.jpg`, `images/exploded.jpg`,
`stickers/images/sheet-8mm-closeup.png`, plus photos of real prints

---

## Summary

Parametric SMD tape magazine for 8, 12 and 16 mm tape. Free FreeCAD source
included, plus a sticker generator for matching labels.

## Description

A rebuilt, fully parametric version of the SMD tape magazine. The free
FreeCAD source is included, so you can change the tape width, wall thickness,
channel clearance, spring bore and lid fit from a single colour-coded
spreadsheet.

**What's included**
- Print-ready STLs: body and slider for 8 / 12 / 16 mm, and one lid that fits
  all three
- The parametric FreeCAD model (FreeCAD 1.1+)
- Rails from the two earlier versions, unmodified, so you can pick either:
  Lord Asdi's (100 / 176 / 300 mm) or OneGeekGuy's O-ring rail with end cap
  (untested with this magazine)
- A sticker generator: front + top labels per part with
  value, package and QR code, laid out on A4

**Print in PETG only.** The lid snaps on with eight small pegs; PLA is too
brittle for them.

**Print settings** (0.4 mm nozzle): 0.25 mm layers, 3 walls, 3 top / 3 bottom
shells, 8–10% gyroid infill (a little infill makes the print more reliable),
no supports. The STLs are pre-oriented with the
chamfered face down.

**Tune your filament profile first**, especially bridging and cooling. Sagging
bridges or under-cooled overhangs in the small latch sockets and pegs are the
usual cause of fitment problems.

**Loader (recommended):** print Robin's SMD Magazine Loader,
https://www.printables.com/model/468303-smd-magazine-loader. It makes
refilling a magazine quick and easy. These magazines are compatible with it,
unlike the design they were remixed from.

**Fitting the lid:** press it on evenly with something flat and stiff over it
(e.g. a ~3 mm mild steel plate) so all eight pegs snap in together, not one
corner at a time.

**Per magazine:** 1 body, 1 slider of the same width, 1 lid, 1 spring. The
spring bore is 8 mm deep, for a longer spring than the original's 0.3 × 4 ×
20 mm. Set `spring_pocket` to 5 in the model to use that one instead.

**Customising:** open `smd-tape-magazine.FCStd` (keep the three .FCStd files
in one folder), double-click `Parameters`, change the green cells, press
Ctrl+R, and export the `Magazine`, `Lid` and `Slider` bodies.

**Stickers:** print them on glossy peel-off sticker paper, at your printer's
highest quality setting, at 100% scale. Before a full sheet, print the QR scan
test sheet and scan it with your phone: codes this small depend on print
resolution.

**Source & sticker generator:** https://github.com/im-AMS/smd-tape-magazine

**Credits**
- Based on *SMD Component Tape Magazine (8, 12, 16mm)* by **Lord Asdi**
  (CC BY 4.0). The outline was traced from it and the model rebuilt as a
  parametric design with reworked latches, sockets and slider.
- Inspired by **robin7331**'s Gen 2 SMD magazine. His original *SMD Component
  Magazines* is the design Lord Asdi's version builds on. Gen 2 hasn't been
  released as open source; this is an open, parametric take on the idea.
- Rails: Lord Asdi (CC BY 4.0) and OneGeekGuy (CC BY-NC 4.0), included
  unmodified with their original licenses.

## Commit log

2026-09-23 Initial release: parametric SMD tape magazine + sticker generator
    Parametric FreeCAD model for 8/12/16 mm tape, print-ready STLs, and a
    label generator. Remix of Lord Asdi's SMD Component Tape Magazine
    (CC BY 4.0), inspired by robin7331's Gen 2.
    Model: CC BY-NC-SA 4.0. Sticker code: MIT.
    [body.FCStd, body_12mm.stl, body_16mm.stl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]
2026-09-23 Rename files and model objects, switch stickers to uv, relicense code
    - CAD files: body -> smd-tape-magazine, female_joint -> latch-socket-cutter,
    male_joint -> latch-peg. Links re-pointed and verified.
    - Every object in the model now has a descriptive label (Magazine, Lid,
    Slider, ReelCavity, LatchSockets, ...). Unused Sketch005 removed.
    Geometry identical at 8/12/16 mm.
    - STLs renamed smd-magazine-{body,slider}-{8,12,16}mm, -lid-all-sizes.
    - Sticker generator runs with uv (pyproject.toml + uv.lock). Diagnostic
    scripts renamed; design_test_sheet no longer crashes on short part lists.
    - Sticker code now CC BY-NC-SA 4.0 like the rest of the repo (was MIT).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
    [body.FCStd, female_joint.FCStd, latch-peg.FCStd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]
2026-09-23 New renders, real print profile, rails, sticker examples
    - Renders on a studio background: 8/12/16 lineup, lid-off, exploded lid.
    - Print profile: 0.25 mm layers, 3 walls, 3/3 shells, 8-10% gyroid.
    - print/rails/: Lord Asdi's rails (CC BY 4.0) and OneGeekGuy's O-ring rail
    + cap (CC BY-NC 4.0), unmodified, with attribution.
    - Sticker README shows a real 8 mm sheet, a close-up and the design test
    sheet; stickers marked work in progress.
    [rail_100mm.stl, rail_176mm.stl, rail_300mm.stl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]
2026-09-23 Renders with stickers applied, grey parts, sticker print advice
    - Renders now show real stickers on the magazines (front label on the
    dispensing-end slope, strip in the top label recess) at 8/12/16 mm.
    - Parts rendered in functional greys with a dark slider; warm backdrop.
    - Infill note clarified (helps the print, not the part).
    - Sticker printing advice: glossy peel-off sticker paper, highest quality,
    100% scale.
2026-09-23 Blender renders, LCSC as default supplier, fitting and tuning tips
    - Renders now come from Blender Cycles: perspective camera, soft area
    lights, shadows, plastic and paper materials, AgX Punchy tone mapping.
    Cover (8/12/16 mm with stickers), single-magazine close-up and an
    exploded view showing the lid pegs. JPEG, ~380 KB total.
    - Stickers default to LCSC: supplier name, QR to lcsc.com/product-detail.
    New --supplier flag; Robu (or any supplier) still works via flags.
    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
    [example.csv]
2026-09-23 Printables listing: link the GitHub repo
2026-09-26 Larger left corner chamfer (1.5 -> 2.0 mm), re-export body STLs
    LeftCornerChamfer (Chamfer003) grown to 2.0 mm. Rebuilds cleanly at
    8/12/16 mm; body STLs re-exported (watertight, no self-intersections).
    Slider and lid are unchanged.
    [smd-magazine-body-12mm.stl, smd-magazine-body-16mm.stl, smd-magazine-body-8mm.stl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]
2026-09-26 Stickers: any tape width, per-row supplier, Excel template
    Input
    - Parts list read by header name (any column order), from CSV or .xlsx.
    New columns: feeder (any width, mm), supplier, url.
    - parts-template.xlsx (built by make_template.py): dropdowns, header
    notes, highlights for missing values/links.
    Layout
    - Mixed feeder widths: asks per page / per row / mixed (or --layout).
    CSV order kept unless it costs rows. Cut ticks only on used rows.
    - A value that does not fit its sticker stops the run with an error
    instead of being printed shortened.
    - Two-line values sized to fit between band and qualifier; wrap at
    hyphens as well as spaces.
    - Strip colour bar = 11.875 % of tape width, c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
    [example.csv, parts-template.xlsx]
2026-09-26 Stickers are no longer work in progress
    Printed and in use on 8 mm cartridges, QR codes scan. The WIP notes are
    replaced with a tip to print the QR scan test sheet on your own printer
    and paper before a full sheet.
